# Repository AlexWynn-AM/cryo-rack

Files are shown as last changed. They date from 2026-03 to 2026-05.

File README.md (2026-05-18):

# Cryo Rack System

Cryogenic rack system design and BOM for the CBA-Vertiv collaboration, with applicability to future Adiabatic Machines deployments.

**[Design Package (PDF)](cryo-rack-design-package.pdf)** — Full system design documentation

## Project Goal

Design and procure a cryogenic demonstration rack using off-the-shelf components, targeting a one-month build timeline. The system provides a 4K environment suitable for AQFP processor testing and demonstration.

## Deployments

| Site | Status  | Notes |
|---|---|---|
| Vertiv | Planned | Demo system, primary target |
| CBA | Planned | Independent test infrastructure|
| Adiabatic Machines| Planned | Integration system for Adiabatic Computing|

## Repository Structure

- `bom/` -- Bill of materials in machine-readable YAML, with site-specific overrides
- `decisions/` -- Architecture Decision Records (ADRs) capturing design choices and rationale
- `docs/` -- System architecture, integration notes, and project timeline
- `scripts/` -- Python tooling for BOM analysis, cost rollups, and export
- `specs/` -- Thermal budget, functional requirements, and constraints

## Quick Start

```bash
pip install -r scripts/requirements.lock
python scripts/bom_summary.py bom/bom.yaml
```

`scripts/requirements.lock` pins the full transitive closure for reproducible
environments and is what CI installs. `scripts/requirements.txt` lists the
direct dependencies (also fully pinned with `==`).

### Regenerating the lockfile

When bumping a direct dependency, edit the `==` pin in
`scripts/requirements.txt`, then regenerate the lockfile with
[uv](https://github.com/astral-sh/uv):

```bash
uv pip compile scripts/requirements.txt -o scripts/requirements.lock
```

`pip-compile` from `pip-tools` is an acceptable substitute. Commit both files
together so the lockfile stays in sync with the direct deps.

## BOM Workflow

The master BOM lives in `bom/bom.yaml`. Site-specific overrides (different cryocooler models, shielding configurations, etc.) are in `bom-cba.yaml` and `bom-vertiv.yaml`. Use the summary script to check status, flag missing quotes, and compute cost totals.

## Signal Chain Analysis

The signal chain from the AQFP chip output (~10 uA at 4 K) through wirebond, flex PCB, isolation transformer, cryogenic feedthrough, coax, and room-temperature LNA to the digitizer is modeled in `scripts/signal_chain.py`. It computes per-stage signal amplitude, noise floor, SNR, and bandwidth using Johnson-Nyquist + Friis cascade math.

```bash
python3 scripts/signal_chain.py                       # printable table
python3 scripts/signal_chain.py --json                # JSON for the dashboard
python3 scripts/signal_chain.py --sweep               # SNR vs AQFP drive sweep
python3 scripts/signal_chain_plot.py                  # nominal waterfall plot
python3 scripts/signal_chain_plot.py --scenario worst_loss
python3 scripts/signal_chain_plot.py --scenario worst_noise
```

The waterfall figure (`docs/assets/signal_chain_waterfall.png`) is committed to the repo. Three scenarios bracket the design envelope and are covered by `tests/test_signal_chain.py::TestScenarios`:

| Scenario | Final SNR | Cascaded NF | Bandwidth bottleneck |
|---|---|---|---|
| Nominal | 21.3 dB | 3.37 dB | Room-temp amplifier (1 GHz) |
| Worst loss | 21.4 dB | 7.79 dB | Room-temp amplifier (1 GHz) |
| Worst noise  | 11.0 dB | 6.67 dB | Room-temp amplifier (1 GHz) |

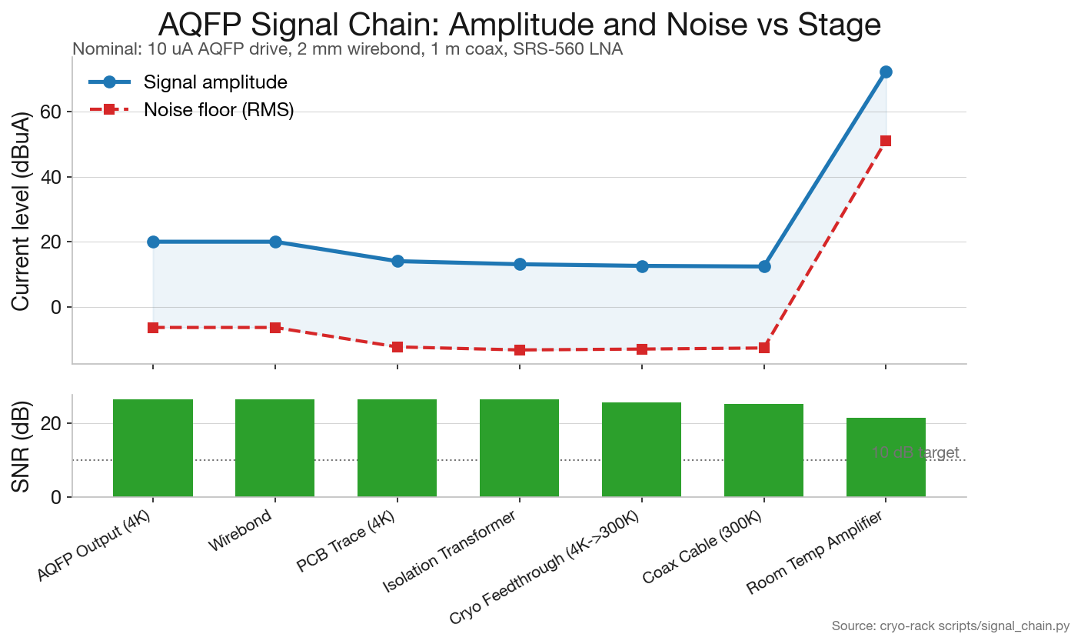
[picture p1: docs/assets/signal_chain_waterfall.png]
Signal chain waterfall — nominal scenario


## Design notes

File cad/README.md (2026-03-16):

# Cryostat CAD Model

FreeCAD 3D model of the cryo-rack cryostat system for AQFP testing.

## Folder Structure

```
cad/
├── README.md                    # This file
├── dimensions.fods              # FreeCAD-linked spreadsheet (Flat ODS)
├── build.sh                     # Build script (generates .FCStd files)
├── build-all.py                 # FreeCAD build script
├── parts/
│   ├── rdk-101d-cold-head.py    # → rdk-101d-cold-head.FCStd
│   ├── sample-stage.py          # → sample-stage.FCStd
│   ├── alumina-disk.py          # → alumina-disk.FCStd
│   ├── radiation-shield.py      # → radiation-shield.FCStd
│   ├── vacuum-vessel.py         # → vacuum-vessel.FCStd
│   ├── top-plate.py             # → top-plate.FCStd
│   ├── thermal-straps.py        # → thermal-straps.FCStd
│   ├── wiring.py                # → wiring.FCStd
│   ├── server-rack.py           # → server-rack.FCStd (42U rack frame)
│   └── cna-11r-compressor.py    # → cna-11r-compressor.FCStd
├── assembly/
│   ├── cryostat-assembly.py     # → cryostat-assembly.FCStd
│   └── rack-assembly.png        # Assembly screenshot
├── exports/                     # STEP files for external sharing
│   └── (generated on demand)
└── reference/
    └── BMC401_cryocooler.stp    # Vendor STEP model (SHI BMC401 cryo cooler)
```

## Building the Models

The `.FCStd` files are generated from Python scripts. To build:

### Option 1: Shell script (recommended)
```bash
cd cad
./build.sh           # Build all parts and assembly
./build.sh clean     # Remove generated files
./build.sh export    # Export to STEP format
```

### Option 2: From FreeCAD GUI
1. Open FreeCAD 0.21 or later
2. Open the Python console (View → Panels → Python console)
3. Run: `exec(open('/path/to/cad/build-all.py').read())`

### Option 3: Individual parts
```bash
cd cad/parts
freecadcmd rdk-101d-cold-head.py  # Generates .FCStd file
```

## Opening the Model

1. Build the models first (see above)
2. Open FreeCAD 0.21 or later
3. Open `assembly/cryostat-assembly.FCStd`
4. All parts are included in the assembly file

## Dimension Sources

### RDK-101D Cold Head (SHI Cryogenics)
- **Source:** SHI RDK-101D outline drawing (request from distributor)
- **Total height:** 442 mm (motor housing to 2nd stage tip)
- **Motor housing:** Ø130 mm
- **1st stage flange:** Ø108 mm at 45K
- **2nd stage cold finger:** Ø52 mm → Ø45 mm at 4K
- **CF flange:** DN63CF (CF4.50)

### Vacuum Vessel
- **Source:** Kurt J. Lesker standard CF components
- **Size:** DN200CF (10" CF flanges, ~200 mm ID)
- **Wall:** 304L stainless steel
- **Length:** Calculated from cold head reach + clearances

### Radiation Shield
- **Source:** Custom fabrication (6061-T6 Al)
- **Default size:** Ø180 mm OD × 250 mm height × 2 mm wall
- **Linked to:** `dimensions.ods` for easy updates

### Sample Stage
- **Source:** Custom fabrication (OFHC Cu, gold-plated)
- **Size:** Ø50 mm × 20 mm thick
- **Mounting:** M3 holes for thermal straps and DUT carrier

### Alumina Disk
- **Source:** CoorsTek / Kyocera polycrystalline Al₂O₃
- **Size:** Ø28 mm × 1.5 mm thick
- **Purpose:** Electrical isolation between cold head and sample stage

### CNA-11R Compressor (SHI Cryogenics)
- **Source:** SHI CNA-11RB specifications
- **Size:** 400 × 484 × 540 mm (H × W × D)
- **Weight:** 65 kg
- **Rack units:** 9U
- **Cooling:** Air-cooled
- **Compatible with:** RDK-101D cold head

### Server Rack
- **Source:** Based on Vertiv VR3100 dimensions
- **Size:** 42U, 600 × 1100 mm (W × D)
- **Rail spacing:** 465.1 mm (19" EIA standard)
- **Style:** Open frame for visibility

## Parametric Variables

All envelope dimensions are linked to `dimensions.ods`. Edit the spreadsheet
to update all linked parts automatically.

| Variable | Default | Unit | Description |
|---|---|---|---|
| `vessel_cf_size` | 200 | mm | DN200CF nominal |
| `vessel_id` | 200 | mm | Inner diameter |
| `vessel_length` | 400 | mm | Calculated from cold head |
| `shield_od` | 180 | mm | Radiation shield OD |
| `shield_height` | 250 | mm | Radiation shield height |
| `shield_wall` | 2 | mm | Shield wall thickness |
| `sample_stage_dia` | 50 | mm | Sample stage diameter |
| `sample_stage_thick` | 20 | mm | Sample stage thickness |
| `strap_width` | 15 | mm | Thermal strap width |
| `coax_od` | 2.2 | mm | 0.086" semi-rigid coax |

## Assembly Notes

- Cold head hangs from top plate (motor outside vacuum)
- Radiation shield thermally connected to 1st stage via Cu straps
- Sample stage thermally connected to 2nd stage via Cu straps
- Alumina disk provides electrical isolation at 4K
- All wiring routes: top plate → 40K heatsink → 4K

## Rack Assembly

The cryostat mounts in a standard 42U server rack with the CNA-11R compressor.

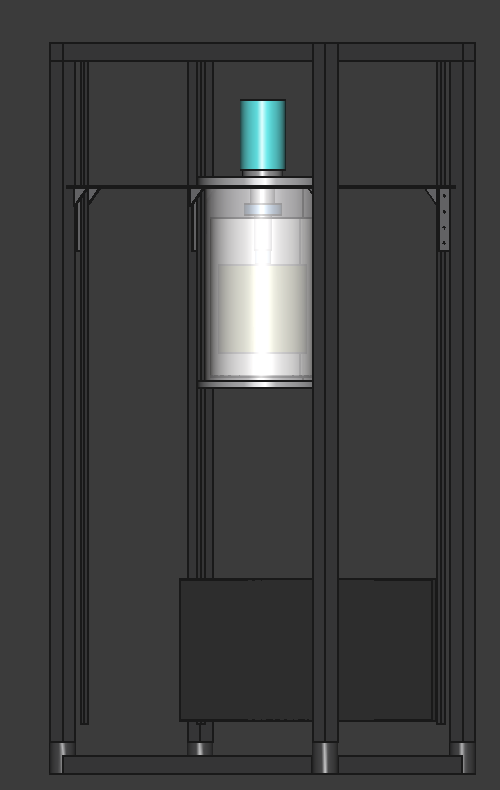
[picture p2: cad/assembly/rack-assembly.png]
Rack Assembly


### Components
- **Server rack:** 42U open frame (600 × 1100 mm), based on Vertiv VR3100
- **Cryostat position:** U35-U42 (near top), mounted on aluminum frame
- **Compressor position:** U1-U9 (bottom)
- **Mounting frame:** 6061-T6 aluminum plate (6mm thick) with center cutout for DN320CF flange

### Rack Specifications
| Parameter | Value |
|---|---|
| Rack units | 42U (1867 mm usable) |
| External width | 600 mm |
| External depth | 1100 mm |
| Rail spacing | 465.1 mm (19" standard) |
| Cryostat clearance | ~40 mm each side between flange and rails |

## Export Instructions

To generate STEP files for external sharing:

### Using build script (recommended)
```bash
./build.sh export
```
Creates `exports/cryostat-assembly.step`

### Manual export
1. Open `assembly/cryostat-assembly.FCStd` in FreeCAD
2. Select all parts in the model tree (Ctrl+A)
3. File → Export → Select STEP format
4. Save to `exports/cryostat-assembly.step`

Individual parts can be exported similarly from their respective files.

## Verification Checklist

- [ ] Cold head dimensions match RDK-101D outline drawing
- [ ] Radiation shield clears 2nd stage + sample stage + wiring
- [ ] Vessel length accommodates full cold head reach
- [ ] Assembly fits within 19" rack width (~450 mm)
- [ ] STEP exports open correctly in other CAD tools

## Calculated Vessel Length

Based on the RDK-101D cold head dimensions and required clearances:

| Component | Z Position | Notes |
|---|---|---|
| Motor top | +245 mm | Outside vacuum |
| CF flange | +25 mm | Mounts to top plate |
| Top plate | 0 mm | **Origin** |
| 1st stage (45K) | -80 mm | Thermal strap attachment |
| 2nd stage tip (4K) | -220 mm | |
| Alumina disk | -222 mm | Electrical isolation |
| Sample stage bottom | -242 mm | Lowest point |

**Recommended vessel length: 300 mm minimum**
- Current design: 400 mm (provides margin for wiring and future changes)
- 50 mm clearance below sample stage

## Related Documents

- `docs/cryostat-assembly.md` — Exploded view diagram and assembly layers
- `docs/thermal-budget.md` — Heat load calculations and shield sizing
- `specs/requirements.md` — System requirements and constraints

## Status

- [x] Folder structure created
- [x] Part scripts written (Python)
- [x] Assembly script written
- [x] Dimension spreadsheet created
- [ ] Generate .FCStd files (run `./build.sh`)
- [ ] Verify dimensions against RDK-101D datasheet
- [ ] Export STEP for Vertiv review

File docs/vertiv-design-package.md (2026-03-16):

---
title: "AQFP Cryo Rack — Design Package"
revision: "0.6"
date: "2026-03-10"
---

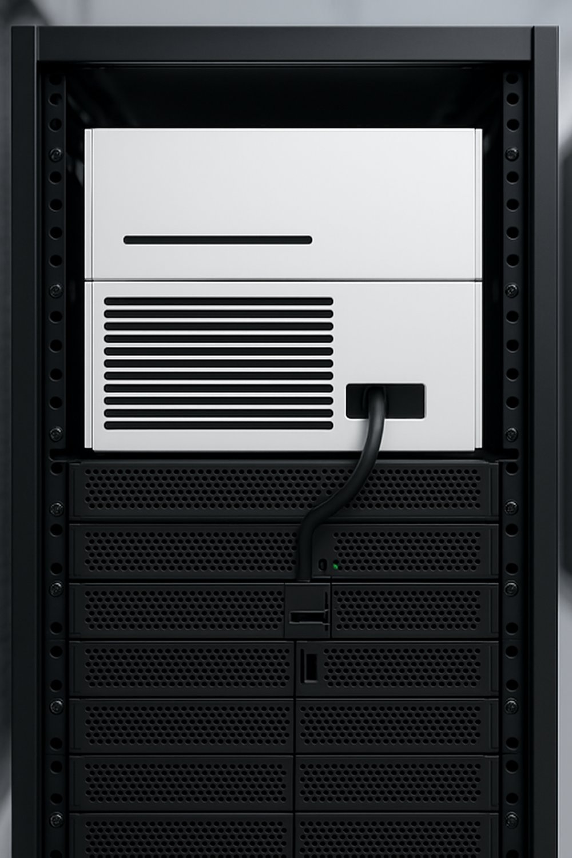
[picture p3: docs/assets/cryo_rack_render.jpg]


**Revision 0.6 — March 2026**

---

## Executive Summary

This document describes the design of a self-contained cryogenic rack
for deploying AQFP (Adiabatic Quantum Flux Parametron) superconducting
processors at 4.2 K. The system is built entirely from off-the-shelf and
standard vacuum components, housed in a 19-inch equipment rack, and designed
for portability between sites.

**Key specifications:**

| Parameter | Value |
|---|---|
| Operating temperature | 4.2 K (second stage), ~40 K (first stage) |
| Cryocooler | SHI RDK-101D + CNA-11RC (GM, air-cooled) |
| Cooling capacity | 100 mW @ 4.2 K, ~6 W @ 45 K |
| Thermal margin | >90% on both stages (with MLI) |
| Power | 120V / 15A standard wall outlet (~2 kW total) |
| Cooling water | Not required |
| Form factor | 19-inch rack (compressor rack-mounted) |
| Vacuum | HiCube 80 Eco turbo station, <10⁻⁸ Torr ultimate |
| Magnetic shielding | FINEMET (40 K), optional Pb foil (4 K) |
| Cooldown time | ~60–90 minutes to 4 K |

**Estimated cost:** ~$52k for the rack build.

**Timeline:** 4 weeks from procurement start to operational, gated by the
12-week cryocooler lead time.

**Deployment plan:** Vertiv (first), then CBA and AM. The system is designed
to be relocated with minimal effort — standard power, air-cooled, modular
construction.

---

## 1. System Architecture

The cryo rack is a self-contained cryogenic deployment platform. A GM cryocooler,
vacuum system, magnetic shielding, and instrumentation are housed in a
standard 19-inch rack, with all signal and power connections accessible from
the front or rear panel.

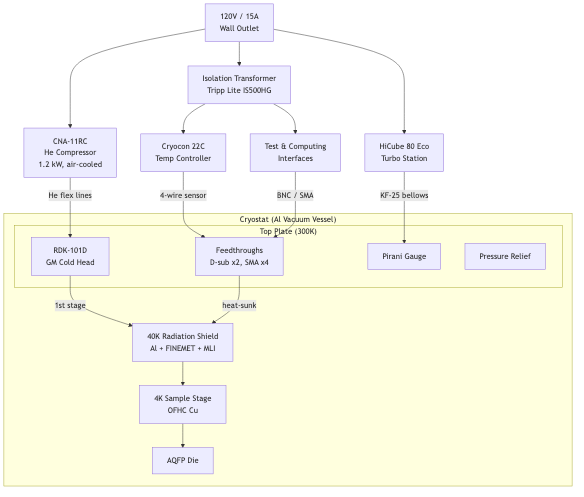
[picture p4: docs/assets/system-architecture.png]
System Architecture


### Thermal stages

The system has three thermal stages:

- **300 K (room temperature):** Vacuum vessel walls, feedthroughs, pump,
  compressor, and all room-temperature electronics.
- **~40 K (first stage):** Aluminum radiation shield with FINEMET
  nanocrystalline magnetic shielding and MLI blankets. Wiring is thermally
  intercepted here.
- **4.2 K (second stage):** OFHC copper sample stage where the AQFP die is
  mounted. Optional superconducting lead foil can be added for residual
  magnetic field attenuation if needed.

### Signal path

DC bias currents are delivered via phosphor bronze twisted pairs, heat-sunk
at 40 K and 4 K. AC clock signals travel on semi-rigid stainless steel
coaxial cables, also thermally intercepted at both stages. All connections
terminate at room-temperature feedthroughs on the cryostat top plate.

### Ground isolation

The cold head body is galvanically continuous with the compressor chassis
through the stainless steel flex lines. The compressor is earth-grounded
through its AC power cord. The GM cycle valve motor produces periodic
current transients (~1 Hz) that propagate through this ground structure.

The system uses two isolated ground domains (see ADR-004):

- **Domain 1 (earth ground):** Building mains → compressor chassis →
  flex lines → cold head → vacuum jacket → rack chassis. Carries
  compressor motor currents. No measurement signals.
- **Domain 2 (isolated measurement ground):** Isolation transformer
  secondary → readout electronics → feedthrough pins → copper backplane
  at 4 K → AQFP circuit ground. Signal and bias currents only.

Isolation is maintained by:

| Location | Component | Function |
|---|---|---|
| 4 K (cold finger) | Polycrystalline alumina disk, 25–30 mm, indium foil both faces | Breaks galvanic path between cryocooler and circuit ground |
| 300 K (feedthroughs) | Ceramic-to-metal hermetic seals | Pins isolated from flange body by design |
| 300 K (power entry) | Tripp Lite IS500HG isolation transformer (500 W, Faraday-shielded) | Isolates readout ground from building mains |
| 300 K (enclosure) | Plastic isolation jacket around cryostat | Prevents accidental contact between cables and vessel |

A plastic enclosure (ABS or acrylic) surrounds the cryostat body,
physically preventing accidental ground contact during assembly and
measurement. All cable routing passes through the enclosure via
insulated grommets at the top plate interface.

---

## 2. Cryostat Assembly

### Design philosophy

All vacuum hardware is standard CF/KF catalog items sourced from multiple
vendors (Kurt Lesker, MDC, Nor-Cal, Ideal Vacuum). Only the radiation shield
and sample stage are custom machined — simple aluminum and copper parts any
machine shop can make. No single-vendor lock-in.

The cryostat is top-loading: the cold head hangs from the top plate with the
cold end pointing down. Feedthroughs are on the top plate or welded side
ports. Pumping connects via KF-25 ports on the vessel body.

### Vacuum vessel material

Two options for the 8" CF vacuum vessel:

| Option | Material | Magnetic (μr) | Procurement | Notes |
|---|---|---|---|---|
| **Aluminum (preferred)** | 6061-T6 Al tube + Atlas bimetal flanges | ~1.00 | Semi-COTS | Al body + SS knife edge; local weld required |
| **Stainless (fallback)** | 304L SS CF nipple | ~1.02–1.10 | COTS (Lesker) | Works with adequate FINEMET shielding |

**Aluminum path:** Purchase Atlas UHV 8" bimetal Al/SS CF weld-neck flanges
and 8" OD 6061-T6 aluminum tube. TIG weld at local shop. Non-magnetic
vessel eliminates trapped flux concerns.

**Stainless path:** Purchase Lesker 8" CF full nipple (304L SS). Faster
procurement but slightly magnetic. The FINEMET shielding (μr ~30,000)
dominates attenuation, so SS vessel permeability is a small contribution
to residual field — acceptable for initial deployment.

### Cross-section

```
  ┌─────────────────────────────────┐
  │         COMPRESSOR              │  CNA-11RC, 120V, rack-mounted
  │         (300 K)                 │
  └──────────┬──────────────────────┘
             │ flex lines (He supply + return)
             │ cold head cable (motor drive)
             │
       ┌─────┴─────┐
       │ COLD HEAD │                      Motor housing sits on top plate
       │  (motor)  │   FT  FT  FT         FT = feedthrough ports (D-sub, SMA)
       │   300K    │   ○   ○   ○          Pirani gauge, pressure relief
       └─────┬─────┘
  ═══════════╪══════════════════════════  ← TOP PLATE (300K)
  ║          │             ○   ○   ║     8" CF multiport cluster flange
  ║    ┌─────┴─────┐               ║     Center bore: CF seal to cold head
  ║    │ 1st stage │               ║     Viton O-ring seal to vessel body
  ║    │  (40 K)   │               ║     (reusable for sample access cycling)
  ║  ┌─┤           ├─┐             ║
  ║  │ └─────┬─────┘ │             ║
  ║  │  strap│  strap│             ║  ← OFHC Cu thermal straps (x2)
  ║  │       │       │             ║
  ║  │  ┌────┴────┐  │             ║
  ║  ├──┤ RAD     ├──┤  ·····      ║  ← RADIATION SHIELD (40K)
  ║  │  │ SHIELD  │  │  :MLI:      ║     6061 Al cylinder + end caps
  ║  │  │ (Al)    │  │  :   :      ║     FINEMET ribbon wrapped on surface
  ║  │  │         │  │  :   :      ║     MLI blankets on outside of shield
  ║  │  │ FINEMET │  │  :   :      ║     Wires heat-sunk here (GE varnish)
  ║  │  │ wrapped │  │  :   :      ║
  ║  │  │         │  │  :   :      ║
  ║  │  │  ┌───┐  │  │  :   :      ║
  ║  │  │  │2nd│  │  │  :   :      ║  ← 2nd STAGE (4K) cold finger
  ║  │  │  │stg│  │  │  :   :      ║
  ║  │  │  ├───┤  │  │  :   :      ║     Cu strap from 2nd stage
  ║  │  │  │   │  │  │  :   :      ║
  ║  │  │  │┌─┐│  │  │  :   :      ║  ← SAMPLE STAGE (4K)
  ║  │  │  ││P││  │  │  :   :      ║     OFHC Cu plate, gold-plated
  ║  │  │  ││ ││  │  │  :   :      ║     Optional Pb foil around DUT
  ║  │  │  │├─┤│  │  │  :   :      ║     Cernox sensor mounted here
  ║  │  │  ││D││  │  │  :   :      ║  ← DUT PCB CARRIER
  ║  │  │  ││U││  │  │  :   :      ║     Wirebonded AQFP die
  ║  │  │  ││T││  │  │  :   :      ║     SMA connectors for RF
  ║  │  │  │└─┘│  │  │  :   :      ║
  ║  │  │  └───┘  │  │  :   :      ║
  ║  │  └─────────┘  │  :···:      ║
  ║  └───────────────┘             ║
  ║                                ║  ← VACUUM VESSEL BODY (300K)
  ║  ○ KF-25 (pump)               ║     6061-T6 Al, 6" OD tube
  ║                                ║     KF ports on top plate
  ║                                ║
  ═════════════════════════════════════  ← BOTTOM PLATE (300K)
                                         Blank 8" CF flange
       │              │
       │              │
  ┌────┴────┐    ┌────┴────┐
  │ HiCube  │    │ Pirani  │
  │ 80 Eco  │    │ gauge   │
  │ (pump)  │    │ CVM211  │
  └─────────┘    └─────────┘
```

### Assembly layers

#### 300 K — Room temperature

| # | Part | Material | Interface |
|---|---|---|---|
| 1 | Equipment rack | Steel | Floor |
| 2 | Compressor (CNA-11RC) | — | 120V wall outlet |
| 3 | Flex lines + cold head cable | SS/Cu | Compressor to cold head |
| 4 | Vacuum vessel body | 6061-T6 Al (or 304L SS) | 8" CF top + bottom (see §2, vessel material) |
| 5 | Top plate | 6061-T6 Al (or 304L SS) | 8" CF, center bore for cold head |
| 6 | Bottom plate | 6061-T6 Al (or 304L SS) | 8" CF blank |
| 7 | Viton O-ring (top plate seal) | Viton | Reusable sample access joint |
| 8 | CF copper gaskets | OFHC Cu | Permanent joints |
| 9 | KF side ports | SS | Welded on vessel body |
| 10 | Pressure relief valve | — | KF-25 port on vessel |
| 11 | Vacuum gauge (Pirani) | — | KF-25 port |
| 12 | HiCube turbo pump station | — | KF-25 bellows hose to vessel |
| 13 | D-sub feedthroughs (x2) | — | CF ports on top plate |
| 14 | SMA feedthroughs (x4) | — | CF ports on top plate |

#### 40 K — First stage

| # | Part | Material | Interface |
|---|---|---|---|
| 15 | Cold head (RDK-101D) | — | CF seal through top plate |
| 16 | Thermal straps (x2) | OFHC Cu braid | 1st stage flange to rad shield |
| 17 | Indium wire | In | Crushed at bolted joints |
| 18 | Radiation shield | 6061-T6 Al | Cylinder + end caps |
| 19 | FINEMET ribbon | Nanocrystalline | Wrapped on rad shield surface |
| 20 | MLI blankets | Al mylar + dacron | Wrapped around shield exterior |
| 21 | Si diode sensor | — | Mounted on shield |
| 22 | Wire heat sinking | GE varnish | Wires anchored to rad shield |

#### 4 K — Second stage

| # | Part | Material | Interface |
|---|---|---|---|
| 23 | Thermal straps (x2) | OFHC Cu braid | 2nd stage to sample stage |
| 23b | Alumina isolation disk | Al₂O₃ (polycrystalline) | Between cold finger and sample stage (see §1, ground isolation) |
| 24 | Sample stage | OFHC Cu | Clamped to cold finger through alumina disk |
| 25 | Lead foil shield (optional) | Pb, 0.1 mm | Wrapped around DUT area |
| 26 | Cernox sensors (x2) | — | 2nd stage + DUT mount |
| 27 | DUT PCB carrier | FR4/Cu | Bolted to sample stage |

### Wiring path

```
External instruments (GS200, 2182A)
       │ DC: BNC/banana cables
       │ RF: SMA cables
       ▼
  ┌─────────────┐
  │ Feedthroughs │  D-sub (DC), SMA (RF) — hermetic, on top plate
  └──────┬──────┘
         │ PhBr wire (DC), SS coax (RF) — inside vacuum
         │
    ┌────┴────┐
    │ 40K     │  Wires thermally anchored (GE varnish on bobbins)
    │ shield  │  Intercepted heat goes to 1st stage
    └────┬────┘
         │
    ┌────┴────┐
    │ 4K DUT  │  DC bias pads + SMA edge-launch on PCB
    │ carrier │  Wirebonded to AQFP die
    └─────────┘
```

### Vacuum path

```
  Atmosphere
       │
  ┌────┴────┐
  │ HiCube  │  Turbo + diaphragm backing pump
  │ 80 Eco  │  KF-25 bellows hose to vessel
  └────┬────┘
       │
  ┌────┴────┐
  │ Vessel  │  SS CF nipple body
  │ interior│  Pirani gauge on KF-25 side port
  │         │  Relief valve on KF-25 side port
  └─────────┘
       ↓ at 4K, cryopumping maintains <1e-6 Torr
```

### Modularity and cryocooler swapping

The top plate is the only cryocooler-specific part. If the cold head
changes (e.g., from RDK-101D to BMC401 or a pulse tube), only the top
plate needs replacement or re-machining (~$400 cost). All other cryostat
components are cold-head agnostic.

---

## 3. Thermal Budget

### Cryocooler capacity

RDK-101D with CNA-11RC compressor at 60 Hz (US power):

| Stage | Temperature | Capacity |
|---|---|---|
| 1st stage | 45–60 K | 3–5 W |
| 2nd stage | 4.2 K | **100 mW** |

### 4 K (second stage) heat budget

| Source | Load (mW) |
|---|---|
| Radiation (40 K to 4 K) | 0.3 |
| DC wire conduction (16x PhBr 36AWG) | 0.1 |
| RF coax conduction (4x SS 0.086") | 2.0 |
| DUT dissipation (AQFP: nW–uW) | ~0 |
| **Total** | **~2.4** |
| **Available** | **100** |
| **Utilization** | **2.4%** |

### 40 K (first stage) heat budget

| Source | With MLI | Without MLI |
|---|---|---|
| Radiation (300 K to 40 K) | 120 mW | 1,800 mW |
| DC wire conduction | 3 mW | 3 mW |
| RF coax conduction | 35 mW | 35 mW |
| **Total** | **~160 mW** | **~1,840 mW** |
| **Available** | **~3,000 mW** | **~3,000 mW** |
| **Utilization** | **5%** | **61%** |

Both stages have large thermal margin. MLI is recommended but not
strictly required at the baseline shield size (100 mm diameter). For
larger shields (200–300 mm), MLI is mandatory — see appendix.

### Shield sizing (how big can we go?)

With MLI, shield size is thermally unconstrained for any rack-mount design:

| Shield (dia x H) | Area | With MLI | Without MLI |
|---|---|---|---|
| 100 x 150 mm | 0.063 m² | 95 mW **(3%)** | 1.4 W (48%) |
| 200 x 300 mm | 0.251 m² | 376 mW **(13%)** | 5.8 W (OVER) |
| 300 x 400 mm | 0.518 m² | 777 mW **(26%)** | 12 W (OVER) |

A 200–300 mm diameter shield provides generous working space for
multiple DUTs and complex wiring, uses only 13–26% of the first-stage
budget with MLI, and fits comfortably in a 19-inch rack (450 mm between
rails).

---

## 4. Cryocooler Selection

### Comparison of quoted options

| Parameter | SHI RDK-101D | SHI RDC-02K | Bama BMC401 | Cryomech PT205 |
|---|---|---|---|---|
| **Type** | GM | GM | GM | Pulse tube |
| **Quoted price** | $27,230 | $37,155 | $13,000 | $42,325 |
| **Lead time** | 12 weeks | 12 weeks | 4 weeks | 36–40 weeks |
| **4 K capacity** | 0.1 W | 0.2 W | 0.16 W | 0.1–0.3 W |
| **40 K capacity** | ~6 W @ 45 K | ~6 W @ 45 K | 3 W @ 45 K | TBD |
| **Min temp** | ~3.5 K | < 2 K | < 2.3 K | 5–6 K |
| **120V / 15A** | **Yes** | **Yes** | **No** (220V) | **Likely yes** |
| **Cooling** | Air | Air | Unconfirmed | Air |
| **Compressor power** | ~1.2 kW | ~1.2 kW | ~1.5 kW | ~1.5 kW |
| **Maintenance** | 10,000 hr | 10,000 hr | 10,000 hr | ~20,000 hr |
| **Vibration** | Moderate (GM) | Moderate (GM) | Moderate (GM) | Low (PT) |

### Selection rationale

**Primary: SHI RDK-101D + CNA-11RC** — 120V plug-and-play, air-cooled,
well-established platform with extensive support. 12-week lead time.

**Upgrade option: SHI RDC-02K + CNA-11RC** — same compressor and rack
integration as the RDK-101D, but 2x the 4 K capacity (0.2 W) and
guaranteed < 2 K base temperature. $10k premium over the RDK-101D.
Relevant if Phase 2 wiring loads grow or sub-4 K operation is needed.

**Backup: Bama BMC401** — half the cost, 4-week delivery, but 220V/50Hz
compressor is not compatible with standard 120V/15A outlets. Under
evaluation for 60 Hz compatibility and potential pairing with SHI CNA-11RC
compressor.

**Not selected: Cryomech PT205** — 36–40 week prototype lead time and
highest cost eliminate it for near-term build. Low vibration and longer
maintenance interval do not materially benefit AQFP electrical testing.
Reconsidering for future permanent installations.

---

## 5. Bill of Materials

<!-- BOM_TABLES -->

*Full BOM is auto-generated from `bom/bom.yaml` (rev 0.6) by the build
script. The tables below show active items only (qty > 0). Reference-only
options (alternative cryocoolers, scroll pump) are excluded from cost
totals.*

---

## 6. Site Requirements — Vertiv

### Power

| Requirement | Specification |
|---|---|
| Outlet type | NEMA 5-15 (standard US 120V / 15A) |
| Circuits needed | 2 recommended (compressor on one, instruments on another) |
| Total power draw | ~2–3 kW |
| Compressor | ~1.2 kW (CNA-11RC), direct to building mains (earth-grounded) |
| Turbo pump | ~150 W (HiCube 80 Eco) |
| Instruments | ~200 W behind isolation transformer (Tripp Lite IS500HG, 500 W) |

No special electrical work required. Standard office/lab outlets are
sufficient. The readout electronics are powered through a rack-mounted
isolation transformer to maintain a clean, isolated measurement ground
(see §1, ground isolation).

### Space

| Requirement | Specification |
|---|---|
| Rack | 19-inch standard, ~20U minimum |
| Rack footprint | ~0.6 x 0.8 m |
| Compressor | Rack-mounted (CNA-11RC fits 19-inch rack) |
| Clearance | Allow ~0.5 m behind rack for cable routing and airflow |
| Cryostat position | Top of rack or adjacent bench |

### Environment

| Requirement | Specification |
|---|---|
| Ambient temperature | 15–30 C (standard lab/office) |
| Cooling water | **Not required** (air-cooled compressor) |
| Ventilation | Standard room HVAC sufficient; compressor rejects ~1–2 kW as heat |
| Floor loading | ~150–200 kg total (rack with compressor + cryostat) |
| Vibration isolation | Not required for AQFP testing |

### Network (optional)

- Ethernet for Cryocon 22C remote temperature monitoring
- USB for instrument control (GS200, 2182A)

### Facility preparation checklist

- [ ] Confirm availability of 2x 120V / 15A outlets near rack location
- [ ] Confirm 19-inch rack (Vertiv may supply) or designate rack location
- [ ] Confirm rack has sufficient depth for compressor (~600 mm)
- [ ] Confirm adequate room ventilation for ~2 kW heat rejection
- [ ] Assign Ethernet drop if remote monitoring desired

---

## 7. Timeline

**Target:** Operational cryo rack within 4 weeks of procurement start.

| Week | Activities |
|---|---|
| **1** | Finalize cryocooler selection. Send RFQs. Order long-lead items. Complete cryostat detailed design. |
| **2** | Place all orders. Commission custom machining (radiation shield, sample stage). Begin rack layout. |
| **3** | Receive and inspect components. Assemble cryostat. Install magnetic shielding. Wire feedthroughs. Room-temperature functional tests. |
| **4** | Leak check vacuum system. Pump down and cooldown. Verify base temperature. Measure residual magnetic field. Functional test with AQFP die (if available). |

### Critical path

The 12-week cryocooler lead time (SHI RDK-101D) gates the overall
schedule. All other components have 1–2 week lead times. During the
cryocooler wait:

- Complete cryostat detailed design using outline drawing dimensions
- Procure and assemble all non-cryocooler components
- Perform room-temperature vacuum and wiring tests
- Prepare DUT carriers and test fixtures

If BMC401 (4-week lead) is selected as backup, the full build can be
completed in approximately 5–6 weeks end-to-end.

---

## 8. Open Items and Risks

### Open actions

| # | Action | Owner | Status |
|---|---|---|---|
| 1 | Re-quote SHI RDK-101D (Quote 5618 expired). Specify CF flange option. | Procurement | Pending |
| 2 | Confirm Cryomech PT205 120V availability when re-quoting | Procurement | Pending |
| 3 | Clarify Bama BMC401 mounting pattern, 60 Hz compatibility, SHI compressor compatibility | Engineering | Pending |
| 4 | Finalize cryostat vessel length from RDK-101D outline drawing dimensions | Engineering | Pending |
| 5 | Detailed top plate port layout (feedthrough count and placement) | Engineering | Pending |
| 6 | DUT PCB carrier design (depends on AQFP die pinout) | Engineering | Pending |

### Risk register

| Risk | Impact | Mitigation |
|---|---|---|
| Cryocooler lead time (12 wk) | Schedule slip | BMC401 backup (4 wk). Pre-assemble all other components. |
| RDK-101D quote expired | Price/availability change | Re-quote immediately. Budget has margin. |
| BMC401 not 120V compatible | Limits portability | Investigate SHI CNA-11RC + BMC401 cold head hybrid. |
| Custom machining delays | 1–2 week slip | Use Protolabs/Xometry for fast-turn; simple parts. |
| MLI installation quality | Higher thermal load | >90% margin on both stages absorbs poor MLI. |
| Vacuum leak at O-ring seal | Pumpdown failure | Turbo pump can maintain vacuum continuously. Viton adequate to 10⁻⁷ Torr. |

---

## Appendix A: MLI Sourcing

10-layer MLI blankets are recommended for radiation shields larger than
150 mm diameter. Material needed for a 200 mm x 300 mm shield:
~2 m² each of reflector and spacer.

| Option | Material | Cost | Lead Time |
|---|---|---|---|
| **DIY (recommended)** | Aluminized mylar (Amazon) + polyester netting (Joann Fabric) | $50–75 | Days |
| **Professional** | Double-aluminized PET (Dunmore) + Dacron netting | $300–500 | 1–2 weeks |
| **Pre-made blankets** | Custom blankets (FrakoTerm, Poland) | $500+ | 2–4 weeks |

DIY MLI has been validated by WSU HYPER lab as comparable in thermal
performance to professional MLI. With >90% thermal margin, DIY is more
than adequate.

MLI adds ~15–30 minutes to pumpdown time due to additional outgassing
surface area. This is a manageable trade-off.

## Appendix B: 3D Printed Parts (PLA at 4 K)

PLA has been validated at 4 K for non-thermally-conductive structural
parts. Low thermal conductivity is a feature for thermal isolation.

**Suitable for 3D printing:**

| Part | Benefit |
|---|---|
| Wire routing bobbins (40 K) | Custom geometry for wire routing |
| DUT mount adapter | Fast iteration as DUT pinout changes |
| Magnetic shield brackets | Hold FINEMET (+ optional Pb foil) in position |
| Thermal isolation standoffs | Low-conductivity spacers between stages |
| Feedthrough strain reliefs | Cable management |

**Must remain metal:** Radiation shield (Al), sample stage (Cu),
vacuum vessel (SS), thermal straps (OFHC Cu).

PLA outgasses at room temperature in vacuum but this is handled by
the turbo pump during pumpdown (adds a few minutes). Once cold,
outgassing drops to near zero.

## Appendix C: CAD Render

FreeCAD model of the complete rack-mounted system:

Rack Assembly

*42U rack with cryostat mounted at U35 (top) and CNA-11R compressor at U1 (bottom).
6mm aluminum mounting frame supports cryostat flange on 19" rails.*

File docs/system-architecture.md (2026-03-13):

# System Architecture

## Overview

The cryo rack is a self-contained cryogenic deployment platform for AQFP superconducting processors. It houses a GM cryocooler, vacuum system, magnetic shielding, and instrumentation in a standard 19" rack, with all signal and power connections accessible from the front or rear panel.

## Block Diagram

```
┌─────────────────────────────────────────────────┐
│  19" Rack                                        │
│                                                   │
│  ┌──────────────┐    ┌────────────────────────┐  │
│  │ Instruments  │    │ Cryostat               │  │
│  │              │    │                        │  │
│  │ Temp Monitor │    │  300K ──── Feedthroughs│  │
│  │ Bias Sources │    │    │                   │  │
│  │ Clock Gen    │    │  40K ──── FINEMET      │  │
│  │ DAQ/Scope    │    │    │      shield       │  │
│  │              │    │   4K ──── Pb shield    │  │
│  │              │    │    │      DUT mount    │  │
│  └──────────────┘    │    └── AQFP die       │  │
│                      └────────────────────────┘  │
│  ┌──────────────┐    ┌────────────────────────┐  │
│  │ He Compressor│◄──►│ Flex lines to cold head│  │
│  │ (+ chiller)  │    └────────────────────────┘  │
│  └──────────────┘                                 │
│  ┌──────────────┐                                 │
│  │ Turbo + Scroll│   Vacuum pumping              │
│  │ Pump Stack    │                                │
│  └──────────────┘                                 │
└─────────────────────────────────────────────────┘
```

## Thermal Stages

The system has three thermal stages. The 300K (room temperature) stage holds the vacuum vessel walls, feedthroughs, and all room-temperature electronics. The first stage at approximately 40K provides radiation shielding and a thermal intercept for wiring; the FINEMET nanocrystalline magnetic shield is wrapped on the 40K radiation shield. The second stage at 4.2K is where the AQFP die is mounted, surrounded by a superconducting lead foil shield for residual field attenuation.

## Signal Path

DC bias currents are delivered via phosphor bronze or manganin twisted pairs, heat-sunk at 40K and 4K. AC clock signals at GHz frequencies travel on semi-rigid or flexible stainless-steel coaxial cables, also thermally intercepted at both stages. Signal readout follows the reverse path. All connections terminate at room-temperature feedthroughs on the cryostat top plate.

## Vacuum

The cryostat is evacuated by a turbomolecular pump backed by an oil-free scroll pump. Once cold, cryopumping on the 4K surfaces maintains vacuum without continuous pumping, though the turbo may remain connected for safety.

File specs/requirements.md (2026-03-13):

# System Requirements

## Functional Requirements

1. Provide a 4.2 K environment with sufficient volume to mount and test AQFP processor die.
2. Cryocooler cooling capacity: >= 100 mW at 4.2 K (second stage), >= 6 W at 45 K (first stage). Thermal budget shows ~16 mW / ~2 W actual load (see `specs/thermal-budget.md`).
3. Ambient magnetic field at the DUT must be < 5 uT (with shielding, target < 100 nT using superconducting Pb shield at 4 K).
4. Support DC bias wiring (16+ conductors, uA precision) from 300 K to 4 K with thermal intercepts at 40 K.
5. Support multi-phase AC clock delivery at GHz frequencies via 4 coax lines from 300 K to 4 K.
6. Support signal readout from 4 K to 300 K with adequate bandwidth.
7. Cool-down time from 300 K to 4 K base temperature should be < 12 hours.
8. System must be self-contained in a standard 19" rack form factor.

## Constraints

- **Timeline:** Procurement and assembly within approximately 4 weeks (target operational by 2026-04-10).
- **Budget:** Estimated ~$75-85k all-in for RDK-101D configuration (see BOM). Use COTS components where possible.
- **Power:** 120 V single-phase preferred for site portability. Total system power ~2-3 kW with RDK-101D air-cooled compressor.
- **Cooling water:** Not required (air-cooled CNA-11C compressor selected per ADR-002).
- **Transportability:** System must be movable between Vertiv, CBA, and AM. Avoid permanent installations. Air-cooled compressor and 120 V operation support this.

## Deployment Sites

1. **Vertiv** — first deployment, primary demo site
2. **CBA** — second deployment, leveraging existing lab infrastructure
3. **AM** — third deployment, shortly after CBA

## Future Requirements (Phase 2)

- Optical I/O path: fiber feedthroughs, VCSEL driver at 300 K, InGaAs photodiode at 4 K.
- Higher channel count for larger AQFP die (may require upgrading to RDK-408D2 class cooler).
- Integration with LPDDR5X memory subsystem at 300 K.

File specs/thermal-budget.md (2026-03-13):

# Thermal Budget

**Moved to [docs/thermal-budget.md](../docs/thermal-budget.md)** — contains
calculated heat loads, shield sizing analysis, and margin assessment.

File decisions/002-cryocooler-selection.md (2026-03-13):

# ADR-002: Cryocooler Selection

**Status:** proposed  
**Date:** 2026-03-10  
**Deciders:** Team

See also: [docs/cryocooler-comparison.md](../docs/cryocooler-comparison.md) for full quoted comparison table.

## Context

The cryo rack needs a two-stage cryocooler to reach 4.2 K for AQFP testing. The system must be operational at Vertiv within ~4 weeks, then move to CBA and AM. Key drivers are lead time, cost, 120 V plug-and-play operation, and sufficient cooling for a minimal-wiring first build.

The original BOM placeholder spec'd ">= 1 W at 4.2 K" (RDK-408D2 class), but the actual thermal budget for the first build is ~16 mW at 4 K and ~2 W at 40 K — well within the capacity of a smaller cooler.

Quotes have been received for four options (all in `bom/quotes/`).

## Options Considered

### Option A: Sumitomo RDK-101D + CNA-11RC — $27,230 (Recommended)

- **4 K capacity:** 0.1 W at 4.2 K
- **40 K capacity:** ~6 W at 45 K
- **Compressor:** CNA-11RC, air-cooled, 100–120 V single-phase, 1.0–1.2 kW
- **120 V / 15 A:** Yes — 1.2 kW well within 1,440 W continuous limit
- **Lead time:** 12 weeks ARO
- **Quote:** SHI Quote 5618, 11/7/2025 (expired — re-quote needed)
- **Type:** GM
- **Pros:**
  - 120 V plug-and-play — works at any site without special power
  - Air-cooled — no chilled water needed
  - Well-established platform, extensive support ecosystem
  - Adequate margin for minimal AQFP test (~16% utilization at 4 K)
  - 10,000 hr maintenance interval, field-serviceable
- **Cons:**
  - 12-week lead time
  - Limited headroom for Phase 2 expansion
  - Moderate vibration at cold stage (GM displacer)

### Option B: Bama BMC401 + HC104F — $12,500 (Backup)

- **4 K capacity:** 0.16 W at 4.2 K
- **40 K capacity:** 3 W at 45 K
- **Compressor:** HC104F — voltage/cooling TBD, must confirm with vendor
- **120 V / 15 A:** Unknown — must confirm. Chinese equipment often defaults to 220 V / 50 Hz.
- **Lead time:** 4 weeks
- **Quote:** Bama email, RMB 90,000 EXW (active)
- **Type:** GM
- **Pros:**
  - Lowest cost by far (less than half of SHI)
  - Fastest lead time (4 weeks)
  - Higher 4 K capacity than RDK-101D (0.16 W vs 0.1 W)
  - Reaches < 2.3 K base temperature
- **Cons:**
  - Less established in Western cryo labs — smaller support ecosystem
  - 120 V / cooling method unconfirmed
  - 1st stage only 3 W @ 45 K (vs 6 W for SHI) — tighter margin at 40 K
  - Flex lines/cables may not be included in quote
  - 10,000 hr maintenance (same as SHI)

### Option C: Cryomech PT205 + CP103A — $42,325 (Reference only)

- **4 K capacity:** 0.1–0.3 W at 5–6 K (prototype)
- **Compressor:** CP103A, 208/220 V 1-ph 60 Hz, air-cooled, ~1.5 kW, 19" rack
- **120 V / 15 A:** No — requires 208/220 V dedicated circuit (NEMA 6-15/6-20)
- **Lead time:** 36–40 weeks ARO (prototype)
- **Quote:** Bluefors CTI Quote 0010037, 10/24/2025 (expired)
- **Type:** Pulse tube
- **Pros:**
  - No moving parts at cold end — low vibration, ~20,000+ hr maintenance
  - Rack-mountable compressor
- **Cons:**
  - Prototype — 36–40 week lead time rules it out for near-term build
  - Most expensive option
  - Requires 208 V — not plug-and-play at arbitrary sites
  - Must be operated near-vertical (pulse tube orientation sensitivity)
  - 5–6 K operation, not guaranteed < 4.2 K

### Option D: SHI RDC-02K + CNA-11RC — $37,155

- **4 K capacity:** 0.2 W at 4.2 K
- **40 K capacity:** ~6 W at 45 K
- **Compressor:** CNA-11RC, air-cooled, 100–120 V single-phase, 1.0–1.2 kW
- **120 V / 15 A:** Yes — same compressor as Option A
- **Lead time:** 12 weeks ARO
- **Quote:** SHI Quote 5617 (expired — re-quote needed)
- **Min temp:** < 2 K (guaranteed)
- **Type:** GM
- **Pros:**
  - 2× the 4 K capacity of the RDK-101D (0.2 W vs 0.1 W) — more headroom for Phase 2 wiring
  - Guaranteed < 2 K base — enables future sub-4 K experiments if needed
  - Same compressor, flex lines, and rack integration as Option A
  - 120 V plug-and-play, air-cooled
- **Cons:**
  - $10k premium over Option A for capacity not needed in the first build
  - Slightly heavier cold head (~6 kg vs ~4 kg)
  - 12-week lead time (same as Option A)
  - Quote expired — re-quote needed

### Previously considered (not quoted)

- **RDK-408D2 + CSW-71D:** ~$40–60k, water-cooled, 208 V, overkill for this build.
- **Cryomech PT410:** ~$50–70k, water-cooled, 208 V, overkill.

## Decision

**Select RDK-101D + CNA-11RC as primary (Option A). BMC401 as backup/fast-start (Option B).**

The PT205 pulse tube is not viable for the near-term build due to 36–40 week prototype lead time, 208 V power requirement, and higher cost. It should be reconsidered for a future permanent installation.

## Rationale

1. **Thermal budget fit:** ~16 mW at 4 K and ~2 W at 40 K — both options cover this with margin.
2. **120 V plug-and-play:** The CNA-11RC runs on a standard wall outlet. The Cryomech CP103A does not. This is a hard constraint for a portable demo rack.
3. **GM reliability is sufficient:** 10,000 hr maintenance interval gives > 1 year continuous before service. For a demo/prototype platform this is more than adequate.
4. **Pulse tube advantages don't help here:** Low vibration matters for scanning probe or optical alignment, not for AQFP electrical testing. The 2x maintenance interval doesn't justify 3x cost and 8x lead time.
5. **BMC401 is the fastest path** if we need to move immediately — 4 weeks, $12.5k. Must confirm 120 V compatibility.

## Consequences

- Cryostat design must be compatible with the RDK-101D cold-head flange (outline drawing in `bom/quotes/`).
- If BMC401 compressor is 220 V only, it needs a step-up transformer or dedicated circuit — reduces its plug-and-play advantage.
- Phase 2 may require a cooler upgrade — design cryostat top plate to accept larger cold heads if practical.
- Water chiller line item not needed (both options are air-cooled).

## Open Actions

1. Re-quote SHI RDK-101D (Quote 5618 expired 12/7/2025)
2. Confirm BMC401 compressor specs: input voltage (120 V / 60 Hz available?), air vs water cooling, flex line inclusion
3. Make go/no-go decision on Option A vs B based on voltage confirmation and schedule

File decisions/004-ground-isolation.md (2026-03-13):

# ADR-004: Ground Isolation Architecture

**Status:** proposed  
**Date:** 2026-03-13  
**Deciders:** Team

See also: [docs/ground_isolation_memo.docx](../docs/ground_isolation_memo.docx) for full analysis.

## Context

The RDK-101D cold head is galvanically continuous with the CNA-11RC compressor chassis through the stainless steel body and flex lines. The compressor chassis is earth-grounded through its AC power cord. The GM cycle valve motor produces periodic current transients (~1 Hz) that propagate through this ground structure.

If the AQFP copper backplane at 4 K is bolted directly to the second-stage cold finger, the circuit ground reference is defined in part by the compressor ground, injecting motor noise into the measurement return path.

Two isolation points are needed: one at the cold interface (4 K) and one at the room-temperature power entry.

## Options Considered

### Option A: Single isolation transformer for everything

Compressor, cold head, and readout electronics all sit behind one isolation transformer, sharing a single isolated ground domain. Eliminates building mains noise and is simple (one transformer, one plug). However, the compressor motor's switching currents still flow through the shared ground bus, and the readout electronics see this as noise on their voltage reference. Trades building mains noise for compressor motor noise.

### Option B: Isolate only the readout (Recommended)

Compressor stays on building mains, earth-grounded for safety and code compliance. Readout electronics get their own small isolation transformer (500 W–1 kW) with a clean, quiet, isolated ground reference. The alumina disk isolates the 4 K backplane from the cold head structure. The only connection between the readout ground domain and the 4 K circuit is the dedicated ground wires through the DC feedthrough pins.

No shared conductor carries both motor current and signal return current at any point in the system. This is the standard approach used in SQUID magnetometry and other sensitive superconducting measurements.

COTS units: Tripp Lite IS500HG (500 W, 120 V, UL 60601-1, Faraday-shielded, ~$200–300) or IS1000HG (1 kW). Compact enough for a 1U–2U rack shelf.

### Option C: Two separate isolation transformers

Compressor on one isolation transformer, readout on another. Provides maximum isolation from building mains for both, but introduces a ground loop risk. If the compressor's isolated ground and the readout's isolated ground are inadvertently connected through the cryostat body (compressor → flex lines → cold head → vacuum jacket → feedthrough shell → readout ground), a ground loop forms. The alumina disk breaks one leg of that loop, but any feedthrough shield, cable braid, or debug probe touching the vacuum jacket re-establishes it. Two separate isolated ground domains with an accidental single-point connection is worse than a deliberate single-point design. Not recommended.

## Decision

**Select Option B: isolate only the readout electronics.**

Two ground domains with a single, well-defined interface:

- **Domain 1 (earth ground):** Building mains earth → compressor chassis → stainless flex lines → cold head body → cryostat vacuum jacket → rack chassis. Carries compressor motor currents. No measurement signals.
- **Domain 2 (isolated measurement ground):** Isolation transformer secondary → readout electronics ground bus → dedicated ground wires through DC feedthrough pins → copper backplane at 4 K → AQFP circuit ground. Carries only signal and bias currents.

Isolation between domains is maintained by:
- Alumina disk at 4 K (between cold finger and backplane)
- Ceramic seals in hermetic feedthroughs at 300 K (pins isolated from flange body by design)

## Consequences

- **BOM additions:** alumina disk (~$30, off-the-shelf), indium foil for both faces (already in BOM), Tripp Lite IS500HG isolation transformer (~$250).
- **Assembly discipline:** No readout cable shield, coax braid, ground lug, or debug probe ground may touch the cryostat body, vacuum jacket, or rack chassis. Every electrical connection between the readout and the cryostat must pass through the feedthrough pins only. Document this in the integration checklist.
- **Thermal impact:** Alumina disk adds a fraction of a kelvin to the base temperature at the backplane. Negligible given >90% thermal margin.
- **Cryostat assembly change:** Sample stage is no longer bolted directly to cold finger. Stack is now: cold finger → indium foil → alumina disk → indium foil → copper backplane.
- **Feedthrough selection:** Standard ceramic-to-metal hermetic feedthroughs (Ceramaseal, Lesker) maintain isolation by design. Any shielded/coax lines where the shield connects to the flange must be avoided or modified.

## Open Questions

1. Confirm RDK-101D CF flange size (believed CF4.50 / DN63CF) — affects zero-length reducer selection if vessel is upsized.
2. Isolation transformer sizing — 500 W likely sufficient for readout alone; verify total draw of DAC/ADC, bias sources, clock generator.
3. Establish debug access protocol: no scope probe ground or clip lead may touch cryostat body during measurement. Label feedthrough connectors accordingly.

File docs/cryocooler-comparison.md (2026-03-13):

# Cryocooler Options — Quoted Comparison

Last updated: 2026-03-11 (BOM rev 0.7)

## Quoted Options

| Parameter | **Bama BMC401** | **SHI RDK-101D** | **SHI RDC-02K** | **Cryomech PT205** |
|---|---|---|---|---|
| **Type** | GM | GM | GM | Pulse tube |
| **Quoted price** | $13,000 (USD direct) | $27,230 | $37,155 | $42,325 |
| **Lead time** | 4 weeks | 12 weeks | 12 weeks | 36–40 weeks |
| **2nd stage (4.2 K)** | 0.16 W | 0.1 W | 0.2 W | 0.1–0.3 W (prototype) |
| **1st stage** | 3 W @ 45 K | ~6 W @ 45 K | ~6 W @ 45 K | TBD ("not as important") |
| **Min temp** | < 2.3 K | ~3.5 K | < 2 K (guaranteed) | 5–6 K |
| **120 V / 15 A compatible** | **Marginal** — HC104F is 220V/1.5kW; with step-up xfmr draws 12.5A @ 120V (tight on 15A, OK on 20A). 60Hz confirmed. | **Yes** (CNA-11RC, 1.0–1.2 kW) | **Yes** (same CNA-11RC) | **Likely yes** — quote said 208/220V but ~1.5 kW = 12.5A @ 120V; confirm 120V option |
| **Cooling** | TBD — confirm | Air-cooled | Air-cooled | Air-cooled |
| **Rack-mountable compressor** | TBD | Yes (CNA-11 series) | Yes (CNA-11 series) | Yes (CP103A, 19" rack) |
| **Compressor input power** | 1.5 kW (confirmed) | ~1.0–1.2 kW | ~1.0–1.2 kW | ~1.5 kW |
| **Cold head mass** | 8 kg | ~4 kg | ~6 kg | TBD (prototype) |
| **Maintenance interval** | 10,000 hr | 10,000 hr | 10,000 hr | ~20,000+ hr (est.) |
| **Vibration at cold stage** | Moderate (GM) | Moderate (GM) | Moderate (GM) | Low (pulse tube) |
| **Quote status** | Active | Expired — re-quote | Expired — re-quote | Expired — re-quote |
| **Quote ref** | Bama email Oct 2025, $7k+$6k USD | SHI Quote 5618 | SHI Quote 5617 | Quote 0010037, Ticket 72680 |
| **Vendor** | Bama Superconductor (Suzhou) | SHI Cryogenics of America | SHI Cryogenics of America | Bluefors CTI (Cryomech) |

### Alternative Compressor: attocube IGLU

The [IGLU compressor](https://www.attocube.com/en/products/cryostats/compact-mobile-cryogenics/iglu-compressor) is a standalone rack-mountable helium compressor (~$40k est.) confirmed compatible with the RDK-101D cold head. 19" rack form factor, ~1 kW input, air-cooled, orientation-free, oil-free. Natively 230V but at ~1 kW a 120V step-up transformer is trivial (~8.3A). Decouples the compressor from the cold head vendor. However, the CNA-11RC bundled in the SHI quote is $13k and does 120V natively — so the IGLU is 3x the cost for the same function. Mainly interesting for future modularity or if rack density is critical.

### 120 V / 15 A Notes

A standard US NEMA 5-15 outlet supplies 120 V at 15 A (1,800 W max, 1,440 W continuous per NEC 80% rule).

- **SHI CNA-11RC**: 1.0–1.2 kW input. Runs on 100–120 V single-phase. Well within 15 A / 1,440 W continuous. **Plug and play.**
- **Cryomech CP103A**: Quote specified 208/220 V, 1-ph, 60 Hz, ~1.5 kW. However, at 1.5 kW a 120 V version would draw only ~12.5 A — well within 15 A. Cryomech (US manufacturer, Syracuse NY) routinely makes compressors in multiple voltage variants. **Likely available in 120 V — confirm when re-quoting.** If so, this is also plug-and-play.
- **Bama HC104F**: 220 V, **1.5 kW confirmed** (10A Chinese outlet). **60 Hz confirmed OK** — Bama can set before shipping. With a ~$40 step-up transformer (120V→220V, 1.5 kW), draws **~12.5 A @ 120 V**. Exceeds the NEC 80% continuous limit (12 A) on a 15 A breaker, but **fine on a 20 A circuit (NEMA 5-20)**. Much better than the 3 kW / 25 A originally estimated. BMC401 cold head is **NOT compatible** with SHI CNA-11 compressor (different motor drive).

## Pulse Tube vs GM — Reliability & Tradeoffs

### GM (Gifford-McMahon) — BMC401, RDK-101D, RDC-02K

- **Moving parts at cold end**: mechanical displacer with seal, driven by motor.
- **Maintenance interval**: ~10,000 hours (~14 months continuous). Displacer seal and regenerator service.
- **Failure modes**: well-characterized. Seal wear is gradual — performance degrades before failure. Field-serviceable with standard tool kits (SHI includes one in quote).
- **Vibration**: moderate displacement at cold stage (~10–25 μm) due to displacer motion. For AQFP testing this is generally acceptable — AQFP chips are not mechanically sensitive in the way optical cavities or STM tips are.
- **Orientation**: can operate in any orientation (some models have restrictions, but SHI RDK-101D is flexible).
- **Cooldown**: relatively fast. BMC401 < 150 min, RDK-101D typically ~60–90 min.

### Pulse Tube — PT205

- **No moving parts at cold end**: the oscillating gas column replaces the mechanical displacer. All moving parts are in the remote compressor.
- **Maintenance interval**: ~20,000–30,000 hours (~2–3 years continuous). Compressor valve maintenance only.
- **Failure modes**: less wear overall, but when issues occur they tend to be in the rotary valve or compressor — still field-serviceable. Less community experience with the PT205 specifically (it's a prototype).
- **Vibration**: significantly lower at cold stage (no displacer motion). Relevant for vibration-sensitive measurements (scanning probe, optical interferometry), but **not a major differentiator for AQFP electrical testing**.
- **Orientation**: pulse tubes are more sensitive to tilt. Most must operate within ~5° of vertical. This matters for shipping/setup but not for steady-state rack operation.
- **Cooldown**: can be slower than GM for the same capacity due to lower specific cooling at high temperatures.

### Recommendation for This Project

For a demo rack that needs to be stood up fast and moved between sites:

1. **GM is the practical choice.** Shorter lead time, lower cost, simpler logistics (120 V, any orientation).
2. **10,000 hr maintenance is fine** — this is a prototype/demo platform, not a 24/7 production system. Even at 10,000 hr you get > 1 year before first service.
3. **Pulse tube advantages (vibration, maintenance interval) don't materially help AQFP electrical testing.** If we were doing scanning probe microscopy or optical alignment, pulse tube would be worth the premium.
4. **The PT205 being a prototype with 36–40 week lead time eliminates it** from contention for the near-term build regardless.

Pulse tube should be reconsidered for a future permanent installation where unattended multi-year operation and low vibration are priorities.

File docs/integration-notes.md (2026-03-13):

# Integration Notes

Running notes on physical integration, site-specific considerations, and lessons learned during assembly.

## Vertiv Site

- Confirm available utilities: facility power (voltage, phase, amperage), cooling water, compressed air.
- Confirm floor space and rack placement constraints.
- Determine what Vertiv provides vs what we bring (rack, PDU, network, etc.).
- Shipping logistics for cryostat and compressor (heavy, fragile).

## CBA Site

- Existing lab infrastructure that can be reused (instruments, vacuum pumps, etc.).
- Relationship to garage lab cryostat build already in progress.
- Shared vs dedicated equipment policy.

## General Integration Notes

(Add notes here as the build progresses.)

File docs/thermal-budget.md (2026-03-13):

# Thermal Budget — RDK-101D + CNA-11RC

Last updated: 2026-03-11 (BOM rev 0.6)

## Cryocooler Capacity

RDK-101D with CNA-11RC compressor at 60 Hz (US power):

| Stage | Temperature | Capacity |
|---|---|---|
| 1st stage | 45–60 K | 3–5 W |
| 2nd stage | 4.2 K | **0.1 W (100 mW)** |

Note: headline spec (0.2 W) is with larger F-20L/FA-20L compressors.
CNA-11 footnote on SHI datasheet: 0.1 W @ 4.2 K. Use this for budgeting.

## Chamber Geometry (from BOM rev 0.6)

- Vacuum vessel: 6" OD SS tube (~140 mm ID)
- Radiation shield: ~Ø100 mm OD × 150–200 mm tall, 6061 Al
- Sample stage: ~Ø50 mm × 20 mm, OFHC Cu
- MLI: 10-layer aluminized mylar on radiation shield exterior

## 2nd Stage (4 K) Heat Budget

| Source | Parameters | Load (mW) |
|---|---|---|
| Radiation (40K → 4K) | ε≈0.1, A≈0.02 m², σ·(40⁴−4⁴) | 0.3 |
| DC wire conduction (40K → 4K) | 16× PhBr 36AWG, L=0.3m, k≈4 W/mK | 0.1 |
| RF coax conduction (40K → 4K) | 4× SS 0.086", L=0.3m, A_metal≈1.7e-6 m² | 2.0 |
| DUT dissipation | AQFP: nW–μW | ~0 |
| **Total** | | **~2.4** |
| **Available** | | **100** |
| **Utilization** | | **2.4%** |

Dominant load: RF coax conduction. Large margin.

## 1st Stage (40 K) Heat Budget

| Source | Parameters | Load (mW) |
|---|---|---|
| Radiation (300K → 40K) w/ 10-layer MLI | ~1.5 W/m², A≈0.08 m² | 120 |
| Radiation (300K → 40K) without MLI | ε≈0.05 bare, A≈0.08 m² | 1,800 |
| DC wire conduction (300K → 40K) | 16× PhBr 36AWG, L=0.5m, k≈25 W/mK | 3 |
| RF coax conduction (300K → 40K) | 4× SS 0.086", L=0.5m, k≈10 W/mK | 35 |
| **Total (with MLI)** | | **~160** |
| **Total (without MLI)** | | **~1,840** |
| **Available** | | **~3,000** |
| **Utilization (with MLI)** | | **5%** |
| **Utilization (without MLI)** | | **61%** |

MLI is not strictly required but reduces 1st stage load by >10×.
Without MLI the system still works but with reduced margin.

## Assumptions

- Wire lengths: ~0.5 m from 300K to 40K heat sink, ~0.3 m from 40K to 4K
- Phosphor bronze thermal conductivity: ~25 W/mK avg (300K–40K), ~4 W/mK avg (40K–4K)
- SS304 thermal conductivity: ~10 W/mK avg (300K–40K), ~2.5 W/mK avg (40K–4K)
- Emissivities: 0.05 (polished metal), 0.1 (unpolished/mixed surfaces at 4K)
- MLI performance: ~1.5 W/m² (typical for 10-layer at 300K–40K)
- 0.086" SS coax metal cross-section: ~1.7e-6 m² (outer + inner conductor)
- 36 AWG wire cross-section: 1.27e-8 m² per conductor
- AQFP DUT dissipation: negligible (nW–μW)

## Risk Items

1. **More RF cables**: each additional 0.086" SS coax adds ~0.5 mW at 4K
   and ~9 mW at 40K. Could add up to 10 cables before 4K budget reaches
   10% utilization.
2. **Larger DUT package**: if future DUT needs more wiring (e.g., 64-pin
   instead of 16), DC wire conduction roughly scales linearly.
   64 wires × 6 μW = 0.4 mW — still negligible.
3. **Wiring heat-sinking quality**: if 40K heat sink is poor (wires not
   well anchored), some 300K heat leaks directly to 4K. GE varnish and
   proper bobbin wrapping are essential.
4. **MLI installation quality**: crumpled or poorly layered MLI degrades
   performance significantly. If MLI is bad, radiation load approaches
   the "without MLI" case — still within budget but reduced margin.

## Conclusion

The RDK-101D + CNA-11RC is well-matched to this chamber. Both stages
have >90% margin with MLI. The small radiation shield area is the main
reason the budget works so comfortably. There is ample room to add more
wiring or a larger DUT in the future without upgrading the cryocooler.

---

## Appendix A: Radiation Shield Sizing — How Big Can We Go?

### Which stage constrains shield size?

**4K (2nd stage): not constrained by shield size.** For a small object
(sample stage) inside a larger enclosure (radiation shield), heat load
depends on the *object* area, not the enclosure area:
Q = ε_object × σ × A_object × (T_enclosure⁴ − T_object⁴).
Making the shield bigger does not increase the 4K heat load. The 2nd
stage budget is wire-conduction limited (~2 mW for 4 coax + 16 DC wires),
independent of shield geometry.

**40K (1st stage): this is the constraint.** Radiation from the 300K
vacuum vessel wall to the 40K shield scales directly with shield surface
area. Available budget: ~3 W (CNA-11RC, 60 Hz). Using 70% utilization
policy → 2.1 W, minus ~40 mW wires → ~2.06 W for radiation.

### Shield size vs. 1st stage heat load

| Shield (Ø × H) | Area (m²) | Vacuum vessel | With MLI | No MLI (ε=0.05) | No MLI (ε=0.15) |
|---|---|---|---|---|---|
| Ø100 × 150 mm | 0.063 | 6" CF nipple | 95 mW **(3%)** | 1.4 W (48%) | 4.3 W (OVER) |
| Ø150 × 200 mm | 0.129 | 8" CF nipple | 194 mW **(6%)** | 3.0 W (100%) | 8.9 W (OVER) |
| Ø200 × 300 mm | 0.251 | 10" CF nipple | 376 mW **(13%)** | 5.8 W (OVER) | 17 W (OVER) |
| Ø300 × 400 mm | 0.518 | 12–14" CF nipple | 777 mW **(26%)** | 12 W (OVER) | 36 W (OVER) |
| Ø400 × 500 mm | 0.942 | 16" CF nipple | 1.4 W **(47%)** | 22 W (OVER) | 65 W (OVER) |
| Max @ 70% util | ~1.4 m² | ~Ø350 × 1000 mm | 2.1 W **(70%)** | — | — |

### Rack fit check

19" rack: 482 mm panel width, ~450 mm between rails.

| Shield Ø | Vessel OD (approx) | Fits in rack? |
|---|---|---|
| 200 mm | ~250 mm (10") | **Yes** — 200 mm clearance |
| 300 mm | ~350 mm (14") | **Yes** — 130 mm clearance |
| 400 mm | ~450 mm (18") | Tight — needs careful layout |

### Takeaway

With MLI, shield size is **thermally unconstrained** for any rack-mount
design. A Ø200–300 mm shield (generous working space for multiple DUTs,
complex wiring, and magnetic shielding layers) uses only 13–26% of the
1st stage budget and fits comfortably in a 19" rack.

**Without MLI, shield size is tightly constrained.** Even a Ø150 × 200 mm
shield hits 100% utilization with polished surfaces. MLI is effectively
mandatory for any shield larger than the minimum baseline design.

The practical constraints on chamber size are:
1. Vacuum vessel cost and weight (bigger CF = heavier, pricier)
2. Cold head reach (2nd stage cold finger has a fixed length)
3. Rack depth and cryostat mounting logistics

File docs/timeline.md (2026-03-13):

# Project Timeline

**Target:** Operational cryo rack within 4 weeks of project start (by ~April 10, 2026).

## Week 1: Design Finalization & Procurement Start

- Finalize cryocooler selection (ADR required).
- Finalize cryostat approach: COTS vs custom, vendor selection.
- Send RFQs for all long-lead items.
- Complete thermal budget estimates for both stages.
- Order any items with known > 2 week lead times immediately.

## Week 2: Procurement & Fabrication

- Place orders for all major components.
- Design and order custom parts (DUT mount, adapter plates, wiring looms).
- Order magnetic shielding materials.
- Begin rack layout planning (physical arrangement, cable routing).

## Week 3: Assembly & Integration

- Receive and inspect major components.
- Assemble cryostat: cold head mounting, radiation shields, wiring.
- Install magnetic shielding.
- Wire feedthroughs and test at room temperature.
- Assemble rack: mount instruments, route cables, install PDU.

## Week 4: Cooldown & Commissioning

- Leak check vacuum system.
- Pump down and begin cooldown.
- Verify base temperature at both stages.
- Measure residual magnetic field at DUT location.
- Basic functional test with AQFP die (if available).
- Document as-built configuration.

## Critical Path Items

These are the items most likely to gate the schedule:

1. Cryostat / vacuum vessel (longest lead if custom; COTS may ship faster)
2. GM cryocooler cold head (typically 2-6 week lead)
3. Custom magnetic shielding (if non-stock dimensions)
4. Electrical feedthroughs (if high pin count or custom)

## Risk Mitigations

- Identify backup vendors for critical-path items.
- Consider used/refurbished cryocooler equipment to shorten lead time.
- Decouple phases: rack assembly and instrumentation setup can proceed in parallel with cryostat procurement.

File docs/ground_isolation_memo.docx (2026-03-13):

TECHNICAL MEMO

Adiabatic Machines, Inc.

Subject: | Ground Isolation Architecture for AQFP Latching JJ Output Amplifiers
Author: | Alex Wynn / Claude (Anthropic)
Date: | March 13, 2026
Status: | Working document — captures design discussion for future reference
References: | Ground return impedance simulation (shared Gnd, 1Ω coupling); SFQ5ee process design rules

# 1. Problem Statement

The current AQFP output amplifier design uses latching Josephson junction (JJ) amplifiers with differential outputs. On the fabricated test chip, 14 differential amplifiers share a common ground return path. Simulation confirmed that as little as 1 Ω of shared ground return impedance is sufficient to produce majority-vote artifacts, where the switching state of one amplifier influences the output of its neighbors through ground bounce.

The immediate fix identified was bonding more ground pads to reduce the shared impedance. However, this memo documents a more fundamental architectural solution: fully isolated ground domains for each output amplifier, with transformer-coupled inputs from the AQFP logic array.

# 2. System-Level Ground Architecture

## 2.1 Cryocooler Ground Path

In a standard SHI RDK-101D installation, the cold head cylinder is electrically continuous with the compressor chassis through the stainless steel body, the braided stainless flex lines, and the compressor housing. The compressor chassis is earth-grounded through its AC power cord. This means the second-stage cold finger, first-stage heat station, and warm flange are all galvanically connected to AC mains earth. The GM cycle valve motor produces periodic current transients at the cycle frequency (~1 Hz), and these transients propagate through the ground structure.

If the AQFP copper backplane at 4K is bolted directly to the second-stage cold finger, the circuit ground reference is defined in part by the compressor ground, injecting noise directly into the amplifier ground return problem.

## 2.2 Ceramic Electrical Isolation at the Cold Finger

The cold head body is galvanically connected to the compressor chassis through the stainless steel flex lines. There is no practical way to break this path at the warm end or in the flex lines without compromising helium integrity. Isolating the cold head from the vacuum jacket at the warm flange is also ineffective, since the cold head remains connected to the compressor through the hoses regardless. The only useful isolation point is between the second-stage cold finger and the copper backplane.

The solution is to insert an electrically insulating, thermally conductive ceramic disk at this interface. Single-crystal sapphire (Al₂O₃) is the traditional choice, with thermal conductivity of 100–1000 W/m·K at 4K depending on crystal quality. However, polycrystalline alumina is a more practical alternative for this application. Its thermal conductivity at 4K is lower (10–30 W/m·K) but still adequate, since the thermal boundary resistance at the indium foil interfaces dominates over the bulk resistance of the disk. Alumina disks are available off the shelf from CoorsTek, McMaster-Carr, and other suppliers for a few dollars, with lead times of days rather than weeks.

Recommended parameters: 25–30 mm diameter, 1–2 mm thick, polished both faces. Use indium foil (0.1 mm) on both interfaces and apply high clamping force. With indium foil interfaces, thermal boundary resistance is typically below 1 K/W for a 25 mm disk, resulting in a base temperature rise of a fraction of a kelvin depending on total heat load.

With the ceramic break in place, the circuit ground is defined entirely by the room-temperature measurement electronics, brought in through a dedicated ground conductor in the DC wiring harness. The cryostat body, cold head, and compressor are on a separate, isolated ground domain.

## 2.3 Prior Art

This approach is well established in the superconducting electronics and quantum computing communities. Sapphire heat-conducting elements are routinely used in cold-finger cryostats to provide thermal coupling while maintaining electrical isolation between the cold head and the sample stage (see, e.g., Woodcraft et al., "Thermal conductance of pressed metallic contacts augmented with indium foil or solder at sub-Kelvin temperatures"). The dilution refrigerator community uses sapphire breaks as standard practice when isolating millikelvin experiments from the fridge structure. For AQFP circuits operating at 4K (rather than 10–20 mK), the thermal requirements are much less stringent, and polycrystalline alumina is fully adequate.

## 2.3 Feedthrough Considerations

Standard CF-mounted hermetic multi-pin feedthroughs (e.g., Ceramaseal, Lesker) use ceramic-to-metal seals that are inherently electrically isolated from the flange body. This means individual pins do not short to the cryostat structure, preserving the isolation established by the sapphire disk. However, any coaxial or shielded lines where the shield connects to the flange must be checked carefully to avoid inadvertently re-grounding the backplane through the cryostat body.

Fiber feedthroughs are naturally isolated since glass is an insulator.

# 3. Per-Amplifier Ground Isolation

## 3.1 Concept

Each output amplifier is treated as a galvanically isolated module with its own private ground return. The input from the AQFP logic array is transformer-coupled (mutual inductance), which is natural for AQFP since the gates are already transformer-coupled by design. Each amplifier receives its own dedicated +V, –V, and GND wires running all the way back to the room-temperature electronics as a separate twisted triple.

In this architecture, the return current for amplifier N flows exclusively on amplifier N’s private GND wire. There is no shared impedance between amplifiers. The ground bounce coupling mechanism identified in simulation ceases to exist.

## 3.2 On-Chip Ground Plane Partitioning

If the on-chip ground plane (M0 in SFQ5ee) is left continuous under all amplifiers, bringing out separate ground wires does not fully solve the problem. The bias current would have two return paths: through the dedicated wire, and through the on-chip ground plane to a neighboring amplifier’s ground wire. Even though the ground plane is superconducting (zero DC resistance), it still has inductance, and at the switching frequencies of the latching JJs, inductive current division routes a fraction of the return current through the shared path. This shared path encloses magnetic flux, which can couple into nearby AQFP gates.

The solution is to split the on-chip ground plane into isolated islands, one per amplifier. Each amplifier gets its own ground pad connected only to its own local ground plane region, with no superconducting path to any other amplifier’s ground. The AQFP logic array retains its own continuous ground plane, since AQFP gates do not carry DC bias currents and do not suffer from the same ground bounce mechanism.

## 3.3 Layout Implementation

In SFQ5ee, the ground plane split is implemented as a gap in the M0 layer, typically a few microns wide, drawn around each amplifier cell. The critical layout constraint is the location of the gap relative to the input transformer.

The input transformer has a primary winding (AQFP side, ground return to the AQFP array ground plane) and a secondary winding (amplifier side, ground return to the amplifier’s isolated ground island). The ground plane gap runs between the primary and secondary ground returns. For a planar thin-film transformer with vertically stacked primary and secondary windings (typical in SFQ5ee), the ground plane gap underneath has minimal effect on the transformer coupling coefficient, since the magnetic flux is predominantly confined between the two winding layers rather than in the ground plane.

Care must be taken to ensure that the ground plane gap does not cross underneath any signal line or transformer winding, as this would force return currents to detour around the slot and alter inductance values. Since each amplifier is a self-contained cell with the input transformer at one end and output pads at the other, the gap can be routed cleanly around the cell boundary.

# 4. Wiring Budget

With 14 amplifiers and 3 wires each (+V, –V, GND), the output amplifier wiring requires 42 conductors. This is well within the capacity of standard 50-pin hermetic CF feedthroughs available from Ceramaseal and Lesker. Additional pins are needed for the AQFP array bias (AC clock lines) and any diagnostic or thermometry wiring.

Thermal load estimate for the amplifier wiring: 42 phosphor-bronze wires (36 AWG, ~100 mm length between first-stage thermalization anchor and 4K backplane) conduct approximately 10–20 μW per wire between 45K and 4K. Total conducted heat: ~0.4–0.8 mW. This is within the RDK-101D’s second-stage budget of 200 mW at 4.2K, though it represents a non-negligible fraction and must be accounted for in the overall thermal budget alongside structural supports, fiber conduction, and any other parasitic loads.

# 5. Cryostat Integration Notes

These notes pertain to the rackmount cryocooler system being developed in the CBA-Vertiv collaboration.

## 5.1 Vacuum Jacket

The cryostat is a standard DN200CF (10″ OD) tube. The RDK-101D cold head mates to one end via a Lesker zero-length reducer flange. The likely part numbers are RF1000X450 (DN200CF to DN63CF, if the cold head is CF4.50) or RF1000X600 (DN200CF to DN100CF, if CF6.00). Confirm the cold head flange size with SHI before ordering.

The opposite end of the tube receives a blank or multi-port DN200CF flange carrying the DC feedthrough(s), fiber feedthroughs, and pump-out port.

## 5.2 Thermal Design Summary

The RDK-101D provides 5 W at 45K (first stage) and 0.2 W at 4.2K (second stage) at 60 Hz. The 10″ bore creates significant radiative surface area at 300K. Multilayer insulation (10–20 layers of MLI) on the exterior of a copper or aluminum first-stage radiation shield is essential. All DC wires and fibers must be thermalized at the first-stage shield before passing to the 4K stage. Structural supports between first stage and second stage should be G10 or carbon fiber standoffs to minimize conductive load.

The copper backplane at 4K serves as the thermal mass, circuit ground plane, and mounting surface for the AQFP chip package. It connects to the second-stage cold finger through the alumina isolation disk described in Section 2.2.

## 5.3 Power Isolation Architecture

The RDK-101D paired with the CNA-11R rackmount air-cooled compressor draws only 1.3–1.5 kW on single-phase 120V. This is small enough that isolating the compressor behind a 1.5–2 kVA isolation transformer is technically feasible. However, a careful analysis of the three possible isolation configurations shows that isolating only the measurement electronics is the preferred approach.

### Option A: Single isolation transformer for everything

In this configuration, the compressor, cold head, and readout electronics all sit behind one isolation transformer, sharing a single isolated ground domain. This eliminates building mains noise and is simple to implement (one transformer, one plug). However, the compressor motor’s switching currents flow through the ground bus of the isolation transformer, and that same ground bus serves as the readout’s voltage reference. The compressor draws amps; the readout measures microvolts. Current flowing through the finite impedance of the shared ground conductor (even the ground bus bar inside the transformer) creates a voltage drop that the readout sees as noise. The alumina disk keeps motor currents out of the 4K backplane, but the room-temperature readout electronics still share a ground with the compressor. This configuration trades building mains noise for compressor motor noise on the measurement ground.

### Option B: Isolate only the readout (recommended)

The compressor stays on building mains, properly earth-grounded for safety and code compliance. The readout electronics (DAC/ADC, current sources for amplifier bias, clock generator) get their own small isolation transformer (500 W–1 kW is sufficient) with a clean, quiet, isolated ground reference. The alumina disk isolates the 4K backplane from the cold head/compressor structure. The only connection between the readout ground domain and the 4K circuit is the dedicated ground wires through the DC feedthrough pins.

In this architecture, there is no shared conductor carrying both motor current and signal return current at any point in the system. The compressor ground domain (earth/building mains) and the readout ground domain (isolated transformer secondary) are connected only through the interwinding capacitance of the isolation transformer, which a Faraday shield reduces to well under 100 pF. This is the standard instrumentation approach used in SQUID magnetometry and other sensitive superconducting measurements.

Suitable COTS units include the Tripp Lite IS500HG (500W, 120V, UL 60601-1, Faraday-shielded, ~$200–300) or the IS1000HG (1 kW) for systems with more readout hardware. These are compact enough for a 1U–2U rack shelf.

### Option C: Two separate isolation transformers

Compressor on one isolation transformer, readout on another. This provides maximum isolation from building mains for both subsystems, but introduces a ground loop risk. If the compressor’s isolated ground and the readout’s isolated ground are inadvertently connected through the cryostat body (compressor → flex lines → cold head → vacuum jacket → feedthrough shell → readout ground), a ground loop forms. The alumina disk breaks one leg of that loop at the cold finger, but if any feedthrough shield, cable braid, or scope probe ground touches the vacuum jacket, the loop is re-established. The area enclosed by this loop picks up 60 Hz and other stray magnetic fields from the lab environment, driving circulating currents that appear as noise. Two separate isolated ground domains with an accidental single-point connection is worse than a deliberate single-point ground design. This configuration is not recommended.

### Summary of ground domains

The recommended system architecture (Option B) has exactly two ground domains with a single, well-defined interface between them:

Domain 1 (earth ground): Building mains earth → compressor chassis → stainless flex lines → cold head body → cryostat vacuum jacket → rack chassis. This domain carries compressor motor currents and is referenced to building earth. No measurement signals exist in this domain.

Domain 2 (isolated measurement ground): Isolation transformer secondary → readout electronics ground bus → dedicated ground wires through DC feedthrough pins → copper backplane at 4K → AQFP circuit ground planes. This domain carries only signal and bias currents. It is isolated from Domain 1 by the alumina disk (at 4K) and by the ceramic seals in the hermetic feedthroughs (at 300K).

Critical discipline: no readout cable shield, coax braid, ground lug, or debug probe ground may touch the cryostat body, vacuum jacket, or rack chassis. Every electrical connection between the readout and the cryostat must pass through the feedthrough pins only, never through the flange housing. Standard insulated ceramic-to-metal hermetic feedthroughs maintain this isolation by design, but it can be defeated accidentally during assembly or debugging.

# 6. Product Architecture Summary

For a 19″ rackmount AQFP cryocooler product built around the RDK-101D and CNA-11R, the complete ground isolation architecture uses only COTS components with no custom fabrication required:

Rack power: CNA-11R compressor on dedicated 20A 120V mains circuit, earth-grounded. Readout electronics behind a 500W–1 kW medical-grade Faraday-shielded isolation transformer (e.g., Tripp Lite IS500HG or IS1000HG) on the same or separate mains circuit.

Cryostat: DN200CF tube, cold head mounted via Lesker RF1000X450 or RF1000X600 zero-length reducer. Multi-port DN200CF flange on opposite end with DC feedthrough(s), fiber feedthroughs, and pump-out.

Cold interface: Polycrystalline alumina disk (25–30 mm diameter, 1–2 mm thick, indium foil both sides) between second-stage cold finger and copper backplane. Breaks galvanic path between cryocooler structure (Domain 1) and circuit ground (Domain 2).

On-chip: Ground plane partitioned into isolated islands per output amplifier. Transformer-coupled inputs from AQFP array. Dedicated +V, –V, GND twisted triple per amplifier through multi-pin feedthrough.

This architecture addresses ground noise at three levels: building mains noise (isolation transformer), compressor motor noise (alumina disk), and inter-amplifier ground coupling (on-chip ground plane partitioning with per-amplifier wiring). All three use inexpensive, off-the-shelf components.

# 7. Open Questions

7.1 Chip-to-backplane interface: Wire bonds vs. spring fingers. Wire bonds are proven in the SCE world but create discrete, high-inductance ground contacts. Spring fingers (BeCu, gold-plated) can provide area-contact grounding across the chip backside, reducing ground path inductance. Spring fingers are also more compatible with swappable modules for a production system. Contact resistance at 4K needs characterization; gold plating on both surfaces is recommended.

7.2 Ground return wiring topology: The current plan is dedicated per-amplifier twisted triples through a multi-pin feedthrough. An alternative is a thick superconducting (NbTi) ground bus from the backplane to a high-current single-conductor feedthrough, but this adds thermal conduction load and complexity. The multi-pin approach with distributed ground pins (every 3rd–4th pin) is likely sufficient given the small switching energies of latching JJ amplifiers.

7.3 Backplane ground topology: Consider whether the copper backplane should be partitioned into quiet (amplifier) and noisy (clock distribution) zones with controlled interconnection (star ground), mirroring the on-chip ground plane partitioning. This prevents AC clock transients from coupling into the amplifier ground returns at the board level.

7.4 Confirm RDK-101D CF flange size: Believed to be CF4.50 / DN63CF based on the 130 mm body envelope, but the SHI datasheet with dimensional drawings is not publicly available. Confirm with SHI sales engineering before ordering the zero-length reducer.

7.5 Isolation transformer sizing: 500W is likely sufficient for the readout electronics alone. Verify total power draw of DAC/ADC boards, clock generator, bias current sources, and any rack-mounted amplifiers. Allow 20–30% headroom for inrush and future expansion. Medical-grade (UL 60601-1) units with Faraday shields are preferred for the low leakage current specification (<100 μA).

7.6 Debug access protocol: Establish a clear lab protocol that no scope probe ground, clip lead, or cable shield may be connected to the cryostat body or rack chassis during measurement. This is the most likely failure mode for the ground isolation architecture. Consider labeling feedthrough connectors and providing insulated BNC-to-feedthrough adapters as part of the system.

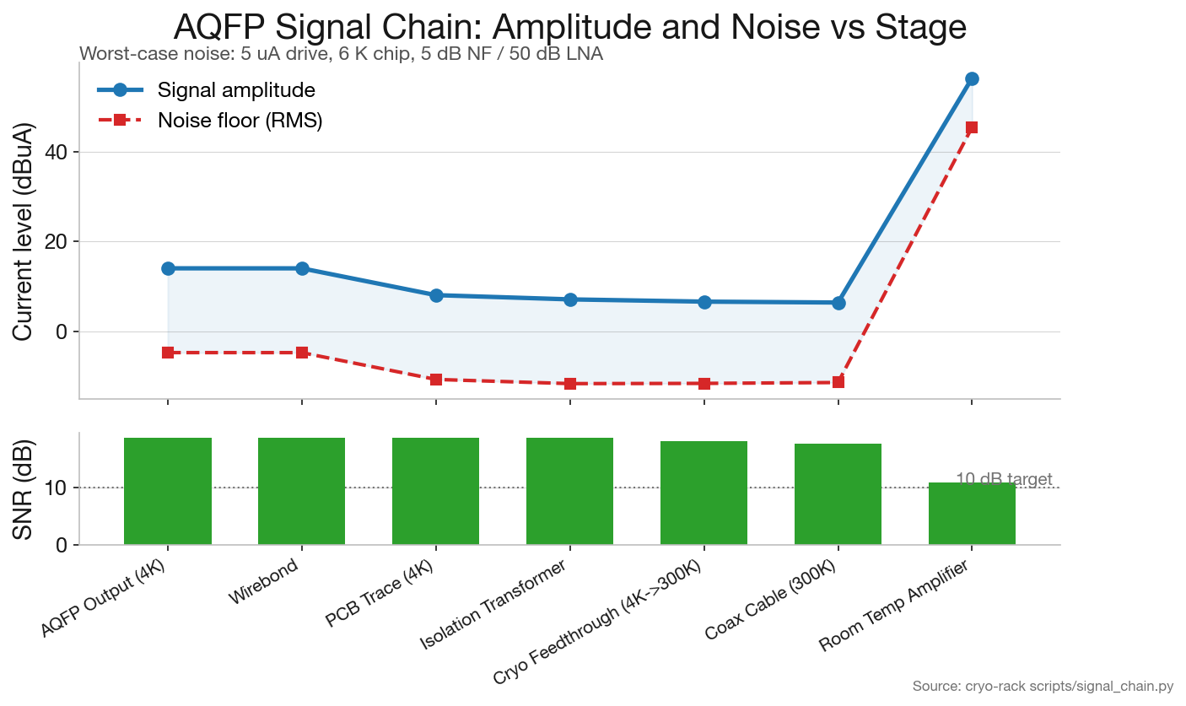
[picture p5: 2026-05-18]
docs/assets/signal_chain_waterfall_worst_noise.png

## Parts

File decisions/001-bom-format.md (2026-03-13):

# ADR-001: BOM Format and Tooling

**Date:** 2026-03-10
**Status:** accepted
**Deciders:** Alex Wynn

## Context

We need a bill of materials format that supports version control, diffing, scripted analysis, and eventual export to spreadsheet formats for procurement. The BOM must accommodate multiple deployment sites (CBA, Vertiv, future AM) with shared and site-specific items.

## Options Considered

1. **Google Sheets** -- Familiar, collaborative. Poor version control, hard to script against reliably, no good branching story.
2. **Excel in git** -- Binary diffs are useless. Merge conflicts are unresolvable.
3. **YAML in git with Python tooling** -- Human-readable, excellent diffs, scriptable, supports comments for rationale. Requires a small upfront investment in parsing scripts.

## Decision

YAML in a git repository, with Python scripts for summary, validation, and XLSX export. Site-specific overrides in separate YAML files that reference the master BOM.

## Consequences

Need to maintain the parsing scripts, but Claude Code can handle this with minimal friction. Procurement staff who need spreadsheets get them via the export script. All changes are tracked with full history.

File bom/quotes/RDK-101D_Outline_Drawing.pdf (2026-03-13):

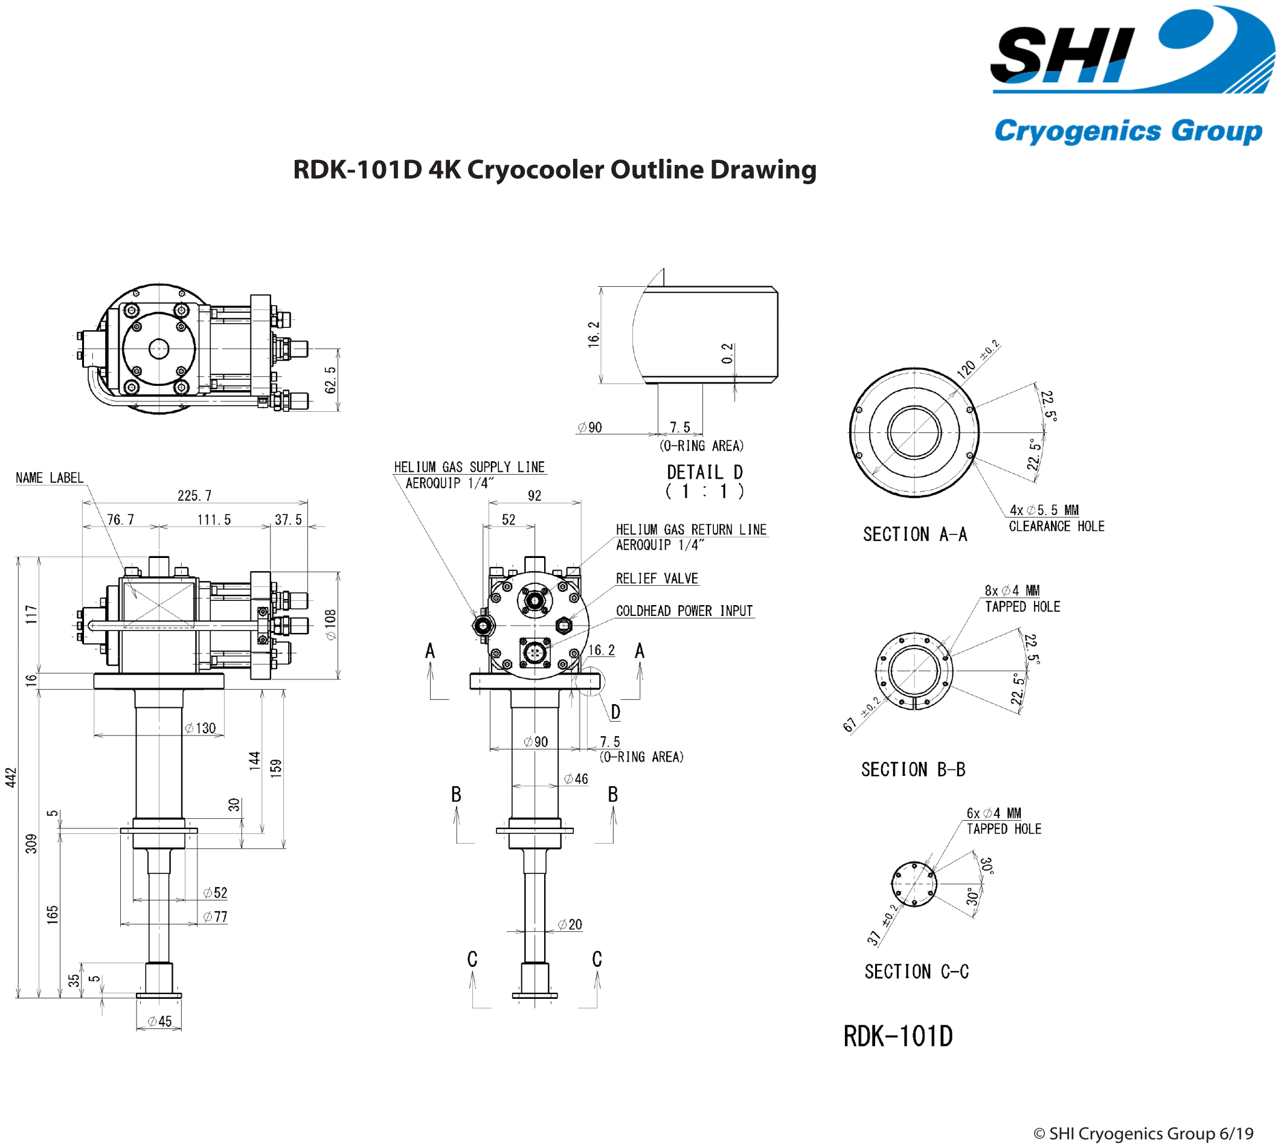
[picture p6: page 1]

RDK-101D4KCryocoolerOutlineDrawing

©SHICryogenicsGroup6/19

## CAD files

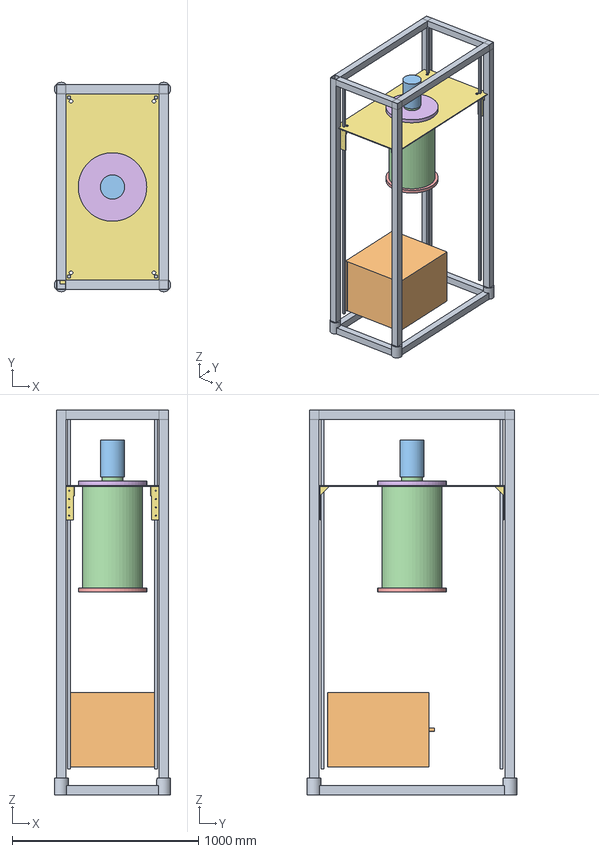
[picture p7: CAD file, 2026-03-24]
cad/assembly/cryostat-assembly.FCStd
625.0 x 1125.0 x 2066.9 mm
ServerRack
CNA11R_Compressor
ColdHead_Motor
ColdHead_CFFlange
ColdHead_Transition
ColdHead_1stStage
ColdHead_2ndTube
ColdHead_2ndTip
AluminaDisk
SampleVolume
RadiationShield
VacuumVessel_Body
VacuumVessel_BottomFlange
TopPlate
MountingFrame

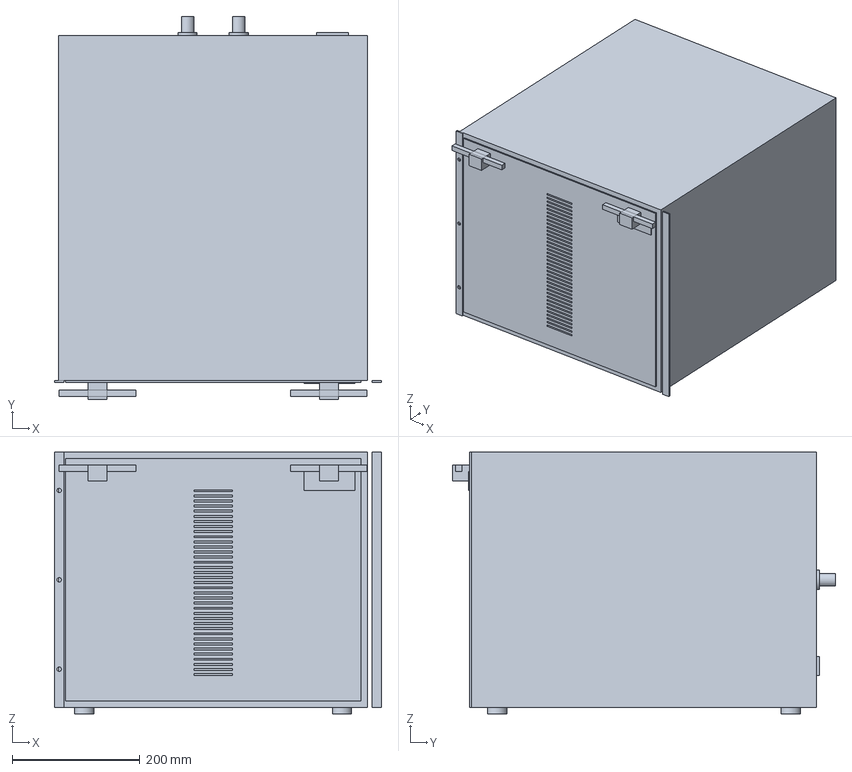
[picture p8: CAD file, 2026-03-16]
cad/parts/cna-11r-compressor.FCStd
512.6 x 600.0 x 410.0 mm

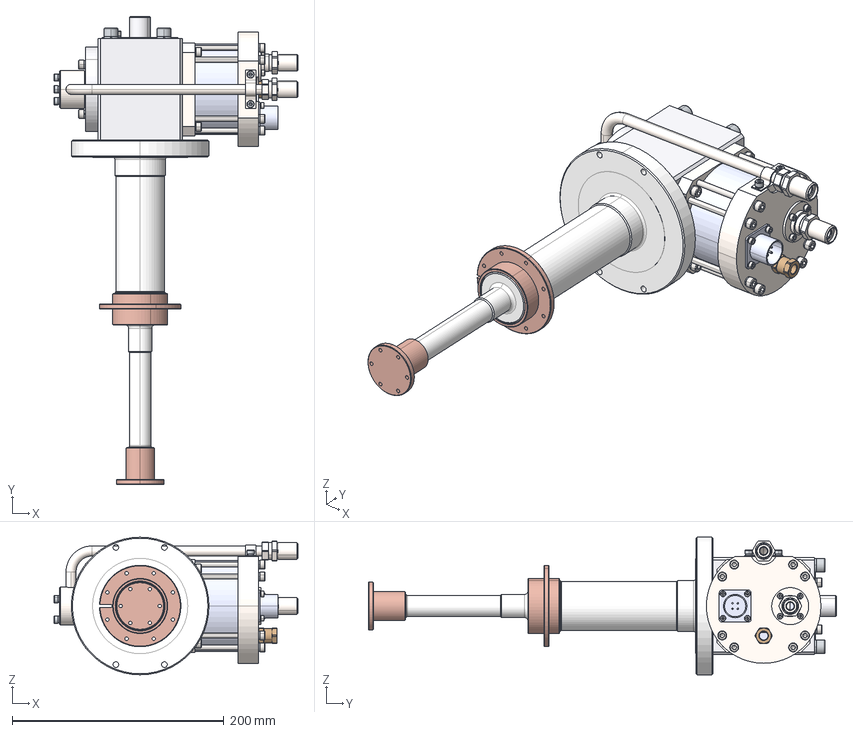
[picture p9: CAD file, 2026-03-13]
cad/reference/BMC401_cryocooler.stp
230.5 x 442.5 x 130.0 mm
SD02010239 O________ x 2
SD01055032 ____________ x 2
SD01021104 _________________M5*30 x 12
SD01042003 _______________5 x 20
SD01042005 _______________M8 x 4
SD01027004 _________________1 x 4
SD01042002 _______________4 x 5
SD01021002 _________________GB70.1-2008 M4__8 x 2
SD01011002 _________________M4*30 x 3
MA46020014 ____
SD02010581 ______
hexagon socket head cap screws gb_GB70.1-2000 M3X6 x 8
SD01042001 _______________3 x 8
MA46020202 ______________
SD02010493 __________ x 7
SD01027005 _______________70 x 8
MA46010001 ________
MA46010002 ________
MA46050003 ________
MA46050002 ________
MA46050001 ____
MA46020203 __________
MA46020201 ____________
MA46020104 ________
SD02010253 O________ _1
MA46020105 ________
SD01051048 O________
SD01051046 O________
SD01055095 __________
MA46020103 ____
MA46020102 ____
MA46020101 ____

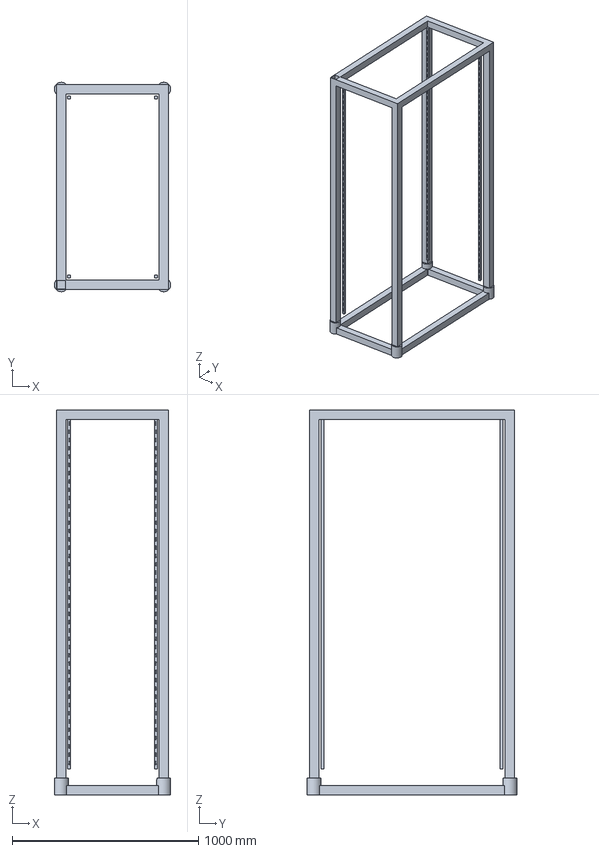
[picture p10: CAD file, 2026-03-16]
cad/parts/server-rack.FCStd
625.0 x 1125.0 x 2066.9 mm

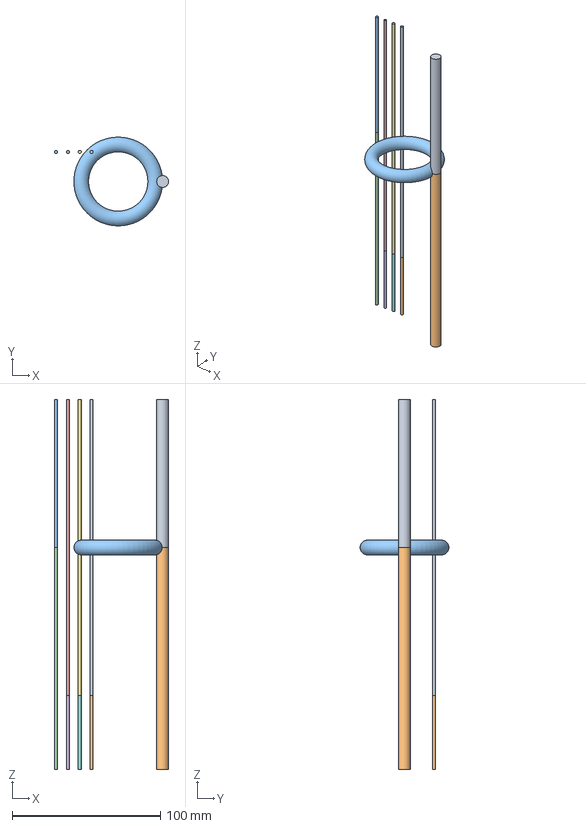
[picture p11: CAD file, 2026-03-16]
cad/parts/wiring.FCStd
77.1 x 60.0 x 250.0 mm
WireLoom_300K_40K
WireLoom_40K_4K
Coax1_300K_40K
Coax1_40K_4K
Coax2_300K_40K
Coax2_40K_4K
Coax3_300K_40K
Coax3_40K_4K
Coax4_300K_40K
Coax4_40K_4K
Heatsink_40K

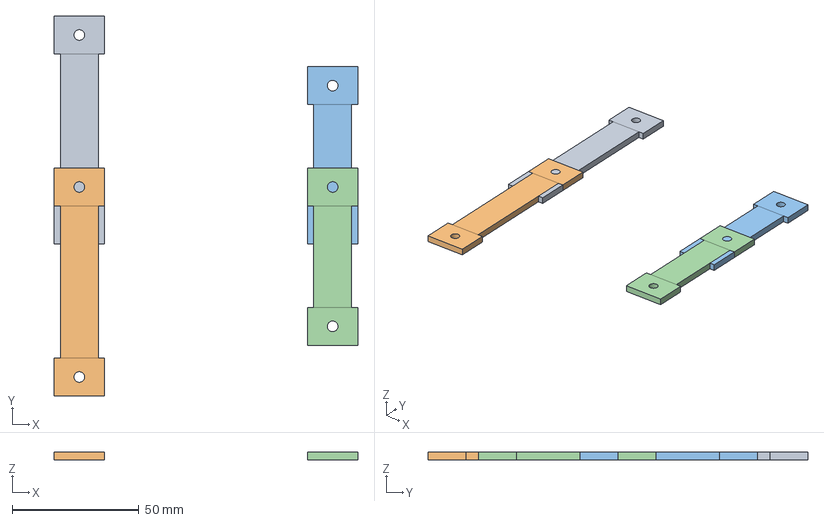
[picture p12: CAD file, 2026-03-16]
cad/parts/thermal-straps.FCStd
120.0 x 150.0 x 3.00 mm
Strap_1st_A
Strap_1st_B
Strap_2nd_A
Strap_2nd_B

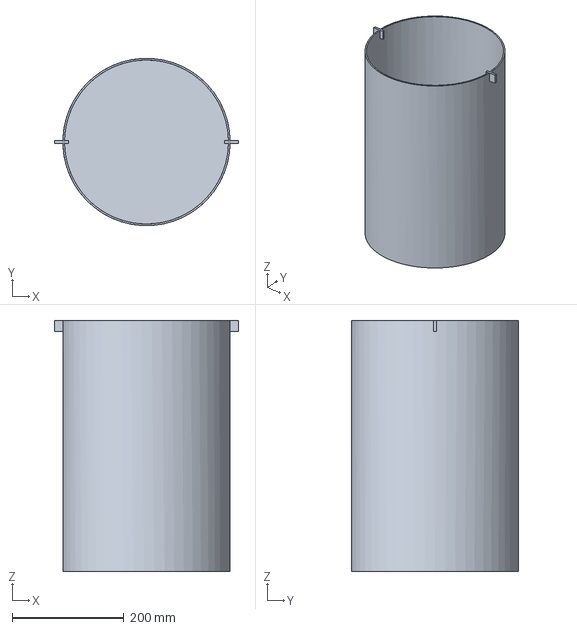
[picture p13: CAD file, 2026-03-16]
cad/parts/radiation-shield.FCStd
330.0 x 299.9 x 450.0 mm

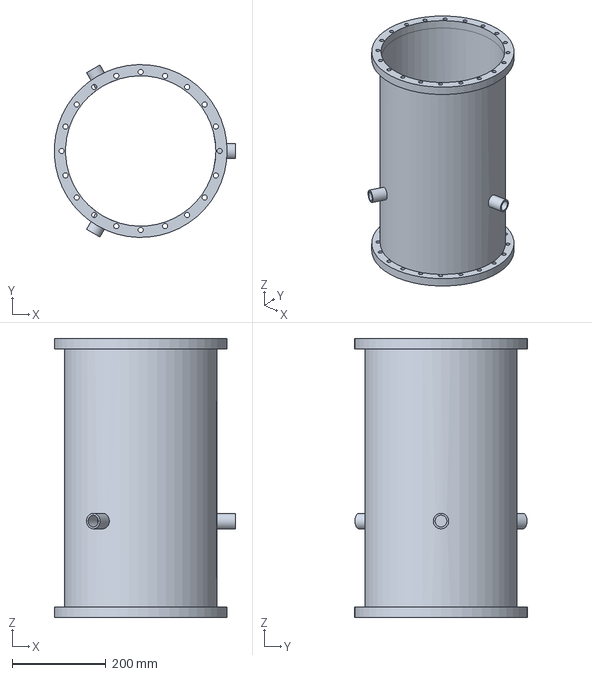
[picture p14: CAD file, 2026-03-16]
cad/parts/vacuum-vessel.FCStd
385.7 x 367.8 x 594.0 mm

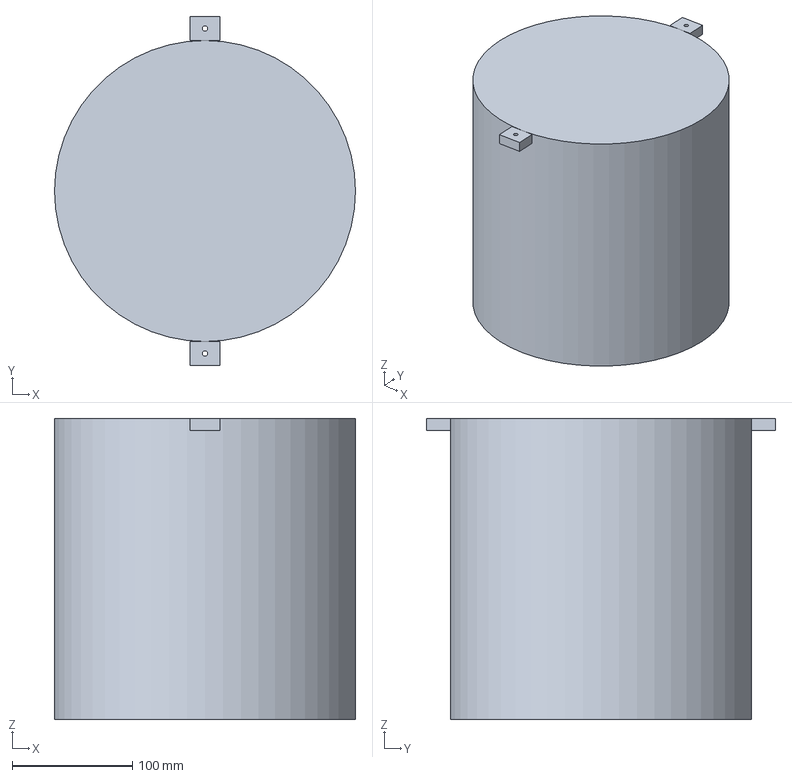
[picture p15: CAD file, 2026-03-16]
cad/parts/sample-stage.FCStd
250.0 x 290.0 x 250.0 mm

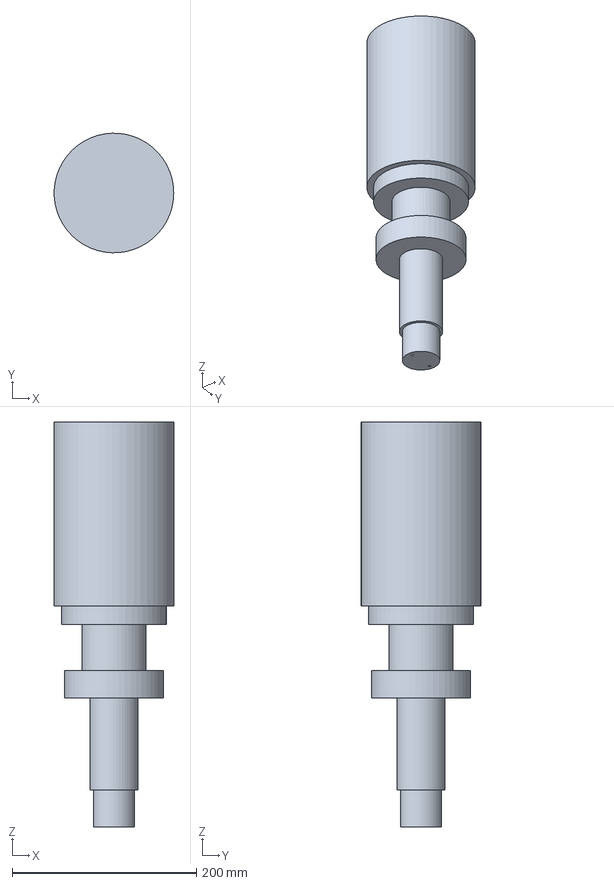
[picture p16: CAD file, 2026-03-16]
cad/parts/rdk-101d-cold-head.FCStd
129.9 x 129.9 x 440.0 mm

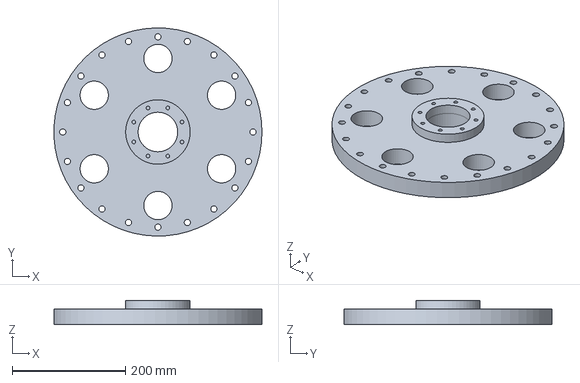
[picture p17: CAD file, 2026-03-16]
cad/parts/top-plate.FCStd
367.7 x 367.9 x 43.0 mm

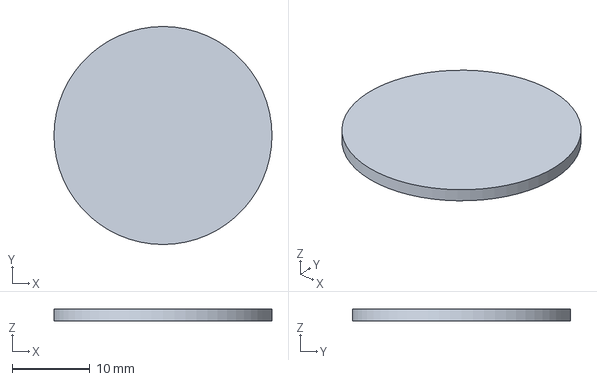
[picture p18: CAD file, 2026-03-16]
cad/parts/alumina-disk.FCStd
28.0 x 28.0 x 1.50 mm

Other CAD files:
cad/exports/cryostat-assembly.step

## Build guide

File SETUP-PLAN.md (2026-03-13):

# Cryo Rack Repo Setup Plan

Execute these steps in Claude Code to bootstrap the repository.

## Step 1: Create and initialize the repo

```bash
mkdir cryo-rack && cd cryo-rack
git init
```

If you want it on GitHub from the start:

```bash
gh repo create adiabatic-machines/cryo-rack --private --clone
cd cryo-rack
```

(Use `--private` since this will contain vendor pricing and system design details.)

## Step 2: Copy in the scaffold files

All the starter files are included alongside this plan. Copy the entire directory contents into your repo root. The structure is:

```
cryo-rack/
├── README.md
├── .gitignore
├── bom/
│   ├── bom.yaml              # Master BOM
│   ├── bom-cba.yaml          # CBA-specific overrides
│   ├── bom-vertiv.yaml       # Vertiv-specific overrides
│   └── vendors/              # Quote PDFs, correspondence
│       └── .gitkeep
├── decisions/
│   ├── template.md
│   ├── 001-bom-format.md
│   └── 002-cryocooler-selection.md
├── docs/
│   ├── system-architecture.md
│   ├── integration-notes.md
│   └── timeline.md
├── scripts/
│   ├── bom_summary.py
│   └── requirements.txt
└── specs/
    ├── thermal-budget.md
    └── requirements.md
```

## Step 3: Install script dependencies

```bash
pip install -r scripts/requirements.txt
```

## Step 4: Verify the BOM tooling works

```bash
python scripts/bom_summary.py bom/bom.yaml
```

This should parse the starter BOM and print a summary table with cost and status rollups.

## Step 5: Start filling in the BOM

The master `bom/bom.yaml` has placeholder entries organized by subsystem. Work through each assembly, filling in part numbers, vendors, costs, and lead times as you get quotes. Use Claude Code to help you add entries, run the summary script, and flag gaps.

## Step 6: Record decisions as you make them

When you choose a specific cryocooler, shielding approach, or wiring scheme, create a decision record in `decisions/` using the template. Even a few sentences is fine. The point is traceability.

## Day-to-day workflow with Claude Code

Typical commands you'll issue:

- "Add a line item to the cryocooler assembly for the compressor water chiller"
- "Run the BOM summary and show me what's still missing quotes"
- "Create a decision record for why we chose the RDK-101D over the PT410"
- "Export the BOM to xlsx for the Vertiv procurement team"
- "What's our total estimated heat load at the 4K stage?"
- "Show me all items with lead time over 3 weeks"

Claude Code can read the YAML, modify it, run the scripts, and generate new documents directly.

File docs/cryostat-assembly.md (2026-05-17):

# Cryostat Assembly — Exploded View (Text)

Last updated: 2026-03-11 (BOM rev 0.5)

## Overview

Top-loading design. Cold head hangs from top plate, cold end points down.
All vacuum hardware is standard CF/KF. Custom parts: radiation shield (Al)
and sample stage (Cu).

```
  ┌─────────────────────────────────┐
  │         COMPRESSOR              │  CNA-11RC, 120V, on floor / rack shelf
  │         (300 K)                 │
  └──────────┬──────────────────────┘
             │ flex lines (He supply + return)
             │ cold head cable (motor drive)
             │
  ═══════════╪══════════════════════════  ← TOP PLATE (300K)
  ║    ┌─────┴─────┐   FT  FT  FT  ║     8" CF multiport cluster flange
  ║    │ COLD HEAD │   ○   ○   ○   ║     FT = feedthrough ports (D-sub, SMA)
  ║    │  (motor)  │               ║     Center bore: CF seal to cold head
  ║    │           │               ║     Viton O-ring seal to vessel body
  ║    │           │               ║     (reusable for sample access cycling)
  ║    ├───────────┤ ← 1st stage   ║
  ║    │  (40 K)   │    flange     ║
  ║  ┌─┤           ├─┐             ║
  ║  │ └─────┬─────┘ │             ║
  ║  │  strap│  strap│             ║  ← OFHC Cu thermal straps (×2)
  ║  │       │       │             ║
  ║  │  ┌────┴────┐  │             ║
  ║  ├──┤ RAD     ├──┤  ·····      ║  ← RADIATION SHIELD (40K)
  ║  │  │ SHIELD  │  │  :MLI:      ║     6061 Al cylinder + end caps
  ║  │  │ (Al)    │  │  :   :      ║     FINEMET ribbon wrapped on surface
  ║  │  │         │  │  :   :      ║     MLI blankets on outside of shield
  ║  │  │ FINEMET │  │  :   :      ║     Wires heat-sunk here (GE varnish)
  ║  │  │ wrapped │  │  :   :      ║
  ║  │  │         │  │  :   :      ║
  ║  │  │  ┌───┐  │  │  :   :      ║
  ║  │  │  │2nd│  │  │  :   :      ║  ← 2nd STAGE (4K) cold finger
  ║  │  │  │stg│  │  │  :   :      ║
  ║  │  │  ├───┤  │  │  :   :      ║     Cu strap from 2nd stage ↓
  ║  │  │  │≈≈≈│  │  │  :   :      ║  ← ALUMINA DISK (electrical isolation)
  ║  │  │  │┌─┐│  │  │  :   :      ║  ← SAMPLE STAGE (4K)
  ║  │  │  ││P││  │  │  :   :      ║     OFHC Cu plate, gold-plated
  ║  │  │  ││b││  │  │  :   :      ║     Pb foil wrapped around DUT area
  ║  │  │  │├─┤│  │  │  :   :      ║     Cernox sensor mounted here
  ║  │  │  ││D││  │  │  :   :      ║  ← DUT PCB CARRIER
  ║  │  │  ││U││  │  │  :   :      ║     Wirebonded AQFP die
  ║  │  │  ││T││  │  │  :   :      ║     SMA connectors for RF
  ║  │  │  │└─┘│  │  │  :   :      ║
  ║  │  │  └───┘  │  │  :   :      ║
  ║  │  └─────────┘  │  :···:      ║
  ║  └───────────────┘             ║
  ║                                ║  ← VACUUM VESSEL BODY (300K)
  ║  ○ KF-25 (pump)               ║     SS CF nipple, 6" OD tube
  ║  ○ KF-25 (gauge)              ║     KF stubs welded on sides
  ║  ○ KF-25 (relief valve)       ║
  ║                                ║
  ═════════════════════════════════════  ← BOTTOM PLATE (300K)
                                          Blank 8" CF flange
       │              │
       │              │
  ┌────┴────┐    ┌────┴────┐
  │ HiCube  │    │ Pirani  │
  │ 80 Eco  │    │ gauge   │
  │ (pump)  │    │ CVM211  │
  └─────────┘    └─────────┘
```

## Assembly Layers (outside → inside, top → bottom)

### 300 K — Room Temperature

| # | Part | Material | Interface | BOM item |
|---|---|---|---|---|
| 1 | Equipment rack | Steel | Floor | rack-utilities |
| 2 | Compressor (CNA-11RC) | - | 120V wall outlet | cryocooler-system |
| 3 | Flex lines + cold head cable | SS/Cu | Compressor ↔ cold head | cryocooler-system |
| 4 | Vacuum vessel body | 304L SS | 8" CF top + bottom | cryostat-vessel |
| 5 | Top plate | 304L SS | 8" CF, center bore for cold head | cryostat-vessel |
| 6 | Bottom plate | 304L SS | 8" CF blank (part of nipple) | cryostat-vessel |
| 7 | Viton O-ring (top plate) | Viton | Sample access joint — reusable | rack-utilities |
| 7b | CF copper gaskets | OFHC Cu | Permanent joints (bottom, feedthroughs) | rack-utilities |
| 8 | KF side ports | SS | Welded on vessel body | cryostat-vessel |
| 9 | Pressure relief valve | - | KF-25 port on vessel | rack-utilities |
| 10 | Vacuum gauge (Pirani) | - | KF-25 port | vacuum-plumbing |
| 11 | HiCube turbo pump station | - | KF-25 bellows hose to vessel | vacuum-plumbing |
| 12 | D-sub feedthroughs (×2) | - | CF ports on top plate | vacuum-plumbing |
| 13 | SMA feedthroughs (×4) | - | CF ports on top plate | vacuum-plumbing |

### 300 K → 40 K — Transition

| # | Part | Material | Interface | BOM item |
|---|---|---|---|---|
| 14 | Cold head (RDK-101D) | - | CF seal through top plate | cryocooler-system |
| 15 | PhBr DC wiring loom | Phosphor bronze | Feedthrough → heat sink at 40K → 4K | thermal-wiring |
| 16 | SS coax cables (×4) | Stainless steel | SMA feedthrough → heat sink at 40K → 4K | thermal-wiring |
| 17 | MLI blankets | Al mylar + dacron | Wrapped around rad shield exterior | thermal-wiring |

### 40 K — First Stage

| # | Part | Material | Interface | BOM item |
|---|---|---|---|---|
| 18 | Thermal straps (×2) | OFHC Cu braid | 1st stage flange → rad shield | thermal-wiring |
| 19 | Indium wire | In | Crushed at bolted joints | rack-utilities |
| 20 | Radiation shield | 6061-T6 Al | Cylinder + end caps | cryostat-vessel |
| 21 | FINEMET ribbon | Nanocrystalline | Wrapped on rad shield surface | magnetic-shielding |
| 22 | Si diode sensor | - | Mounted on 1st stage or shield | temperature-monitoring |
| 23 | Wire heat sinking | GE varnish / Cu bobbins | Wires anchored to rad shield | rack-utilities |

### 4 K — Second Stage

| # | Part | Material | Interface | BOM item |
|---|---|---|---|---|
| 24 | Thermal straps (×2) | OFHC Cu braid | 2nd stage → sample stage | thermal-wiring |
| 25 | Indium wire | In | Crushed at bolted joints | (same as #19) |
| 25b | Alumina isolation disk | Al₂O₃ (polycrystalline) | Between cold finger and sample stage | cryostat-vessel |
| 26 | Sample stage | OFHC Cu | Clamped to cold finger through alumina disk | cryostat-vessel |
| 27 | Lead foil shield | Pb, 0.1 mm | Wrapped around DUT area | magnetic-shielding |
| 28 | Cernox sensors (×2) | - | 1 on 2nd stage, 1 on DUT mount | temperature-monitoring |
| 29 | DUT PCB carrier | FR4/Rogers + Cu | Bolted to sample stage | thermal-wiring |

## Signal Path

```
External instruments (GS200, 2182A)
       │ DC: BNC/banana cables
       │ RF: SMA cables
       ▼
  ┌─────────────┐
  │ Feedthroughs │  D-sub (DC), SMA (RF) — hermetic, on top plate
  └──────┬──────┘
         │ PhBr wire (DC), SS coax (RF) — inside vacuum
         │
    ┌────┴────┐
    │ 40K     │  Wires thermally anchored (GE varnish / Cu bobbins)
    │ shield  │  Intercepted heat goes to 1st stage
    └────┬────┘
         │
    ┌────┴────┐
    │ 4K DUT  │  DC bias pads + SMA edge-launch on PCB
    │ carrier │  Wirebonded to AQFP die
    └─────────┘
```

## Temperature Readout Path

```
  Cryocon 22C controller (rack-mounted, 300K)
       │ 4-wire sensor cables through D-sub feedthrough
       │
       ├── Cernox #1: on 2nd stage cold finger (4K reference)
       ├── Cernox #2: on DUT mount / sample stage (4K at DUT)
       └── Si diode: on 1st stage or rad shield (40K)
```

## Vacuum Path

```
  Atmosphere
       │
  ┌────┴────┐
  │ HiCube  │  Turbo + diaphragm backing pump
  │ 80 Eco  │  KF-25 bellows hose to vessel
  └────┬────┘
       │
  ┌────┴────┐
  │ Vessel  │  SS CF nipple body
  │ interior│  Pirani gauge on KF-25 side port
  │         │  Relief valve on KF-25 side port
  └─────────┘
       ↓ at 4K, cryopumping maintains <1e-6 Torr
```

## MLI (Multi-Layer Insulation) — Sourcing & Installation

**Required for shields larger than Ø150mm.** See thermal budget appendix.
For Ø200–300mm shields, MLI reduces 1st stage radiation load by >10×.

### Material needed

10 layers on a Ø200mm × 300mm shield: ~2 m² each of reflector + spacer.

### Sourcing options

| Option | Reflector | Spacer | Cost | Lead |
|---|---|---|---|---|
| **DIY (recommended)** | Aluminized mylar photo-film (Amazon) | 100% polyester mosquito netting ([Joann Fabric](https://www.joann.com)) | ~$50-75 | Days |
| **Professional** | Double-aluminized PET ([Dunmore](https://www.dunmore.com), Bristol PA) | Dacron netting (cryo supplier) | ~$300-500 | 1-2 wk |
| **Pre-made blankets** | Custom MLI blankets ([FrakoTerm](https://frakoterm.com), Poland) | Integrated | ~$500+ | 2-4 wk |

WSU HYPER lab [tested DIY vs professional MLI](https://hydrogen.wsu.edu/2020/06/16/how-to-make-cryogenic-multi-layer-insulation-mli-shields/)
and found comparable thermal performance after a few layers.
With our >90% thermal margin, DIY is more than adequate.

### Installation notes

- Wear gloves (fingerprint oils reduce reflectivity)
- Stagger seams between layers (avoid thermal short circuits)
- Leave small gaps in seams for pump-out (don't fully tape-seal)
- Use mylar tape on seams, not metal fasteners
- Anchor with pipe cleaners or wire ties (minimal thermal conduction)
- FINEMET goes on the radiation shield surface; MLI wraps over FINEMET
- Adds ~15-30 min to pumpdown time (outgassing from extra surface area)

## 3D Printed Parts (PLA at 4K)

PLA has been validated at 4K for non-thermally-conductive structural parts.
Low thermal conductivity is a feature for isolation. Fast iteration, cheap.

### Print candidates

| Part | Benefit | Notes |
|---|---|---|
| Wire routing bobbins (40K) | Custom geometry for PhBr + coax routing | Replaces machined Cu bobbins |
| DUT mount adapter | Iterate with DUT pinout changes | Sits on Cu sample stage |
| Magnetic shield brackets | Hold FINEMET + Pb foil in position | Inside radiation shield |
| Thermal isolation standoffs | Low-k spacers between stages | Replaces G10 tubes |
| Feedthrough strain reliefs | Cable management from top plate to shield | Replaces zip ties / Kapton |
| Assembly alignment jigs | Temporary fixtures during integration | Don't need to survive cryo |

### Must remain metal

| Part | Reason |
|---|---|
| Radiation shield | Must conduct heat to 1st stage (Al) |
| Sample stage | Must conduct heat to 2nd stage (Cu) |
| Vacuum vessel + top plate | Must hold vacuum (SS) |
| Thermal straps | Must conduct heat (OFHC Cu) |

### Outgassing

PLA outgasses water + volatiles at room temp in vacuum. Manageable:
turbo pump handles it during pumpdown (adds a few minutes). Once cold,
outgassing drops to near zero. Optional: light bake at 50–60°C under
vacuum before cooldown drives off most volatiles. Do not exceed 60°C
(PLA glass transition).

## Ground Isolation

See ADR-004 (`docs/decisions/004-ground-isolation.md`) and `docs/ground_isolation_memo.docx`.

The cold head body is galvanically continuous with the compressor chassis
(through stainless flex lines) and therefore to AC mains earth. The GM
valve motor injects periodic current transients into this ground structure.

**Two isolation points** keep motor noise out of the measurement path:

1. **Alumina disk at 4 K** — polycrystalline Al₂O₃, 25–30 mm diameter,
   1–2 mm thick, indium foil both faces. Inserted between the 2nd-stage
   cold finger and the copper backplane. Breaks the galvanic path between
   the cryocooler structure and the circuit ground.

2. **Isolation transformer at 300 K** — Tripp Lite IS500HG (500 W,
   Faraday-shielded, medical-grade). Powers only the readout electronics.
   Compressor stays on building mains, earth-grounded.

This creates two ground domains:

- **Domain 1 (earth):** mains → compressor → flex lines → cold head →
  vacuum jacket → rack chassis. No measurement signals.
- **Domain 2 (isolated):** isolation transformer → readout electronics →
  feedthrough pins → copper backplane at 4 K. Signal and bias only.

**Assembly discipline:** no readout cable shield, coax braid, or probe
ground may touch the cryostat body or rack chassis. All electrical
connections between readout and cryostat pass through feedthrough pins
only. Ceramic-to-metal hermetic feedthroughs maintain isolation by design.

## Open Design Questions

1. **Vessel length**: depends on RDK-101D dimensions from outline drawing.
   Need: 1st stage to 2nd stage distance + sample space below 2nd stage
   + clearance above 1st stage for MLI/wiring routing.
2. **Top plate port layout**: number and placement of CF sub-ports depends
   on total wire count and whether pumping goes on side or through top.
3. **Radiation shield height**: must clear 2nd stage + sample stage + DUT
   + Pb foil + wiring strain relief. Target ≥120 mm internal height.
4. **FINEMET inside or outside MLI?**: FINEMET on the radiation shield
   surface (at 40K), MLI on outside of FINEMET. FINEMET must be at
   cryogenic temp for best permeability.
5. **Vessel bore size**: current design uses DN160CF (6" OD tube, 8" CF
   flanges, ~140 mm ID). Ground isolation memo describes DN200CF (8" OD
   tube, 10" CF flanges, ~200 mm ID) with a Lesker zero-length reducer
   (RF1000X450 or RF1000X600) for cold head mounting. Larger bore gives
   more space for wiring and radiation shield but increases radiative
   load (MLI mandatory). Resolve before ordering vessel.
6. **RDK-101D CF flange size**: believed CF4.50 / DN63CF based on
   130 mm body envelope. Confirm with SHI before ordering zero-length
   reducer.

---

## Working Render

FreeCAD model of the complete rack-mounted system:

Rack Assembly

*42U rack with cryostat mounted at U35 (top) and CNA-11R compressor at U1 (bottom).
Aluminum mounting frame supports cryostat flange on 19" rails.*

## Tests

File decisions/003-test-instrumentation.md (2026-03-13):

# ADR-003: Test Instrumentation Selection

**Status:** accepted  
**Date:** 2026-03-10  
**Deciders:** Team

## Context

The cryo rack needs DC bias sourcing and voltage readout for AQFP superconducting circuit characterization. Superconducting circuits are extremely sensitive to electromagnetic interference — standard bench supplies (Rigol, Keysight bench PSUs) and general-purpose SMUs (Keithley 2400 series) are too noisy. Instrument selection must reflect what the SC electronics community actually uses.

Phase 1 is basic IV characterization and functional bring-up. Phase 2 is low-speed digital functional testing (1 kHz – 1 MHz pattern generation and capture).

## Phase 1: Characterization

### Minimum Viable — Yokogawa GS200 + Keithley 2182A

- **GS200** (~$4k): Low-noise DC source, ±32 V / ±200 mA, 100 µVp-p noise. Industry standard across quantum/SC labs for Josephson junction biasing.
- **2182A** (~$6.7k): Dual-channel nanovoltmeter, 1 nV sensitivity, 15 nV p-p noise at 1s. The standard readout for SC voltage measurements.
- Together they cover single-channel IV curves and basic characterization.

### Budget Alternative — GS200 + Keithley DMM6500

- **DMM6500** (~$1.9k): 6.5-digit DMM, 100 nV sensitivity. Can replace the 2182A for initial bring-up and functional checks.
- Tradeoffs: 10x worse noise floor, no delta-mode. Fine for "does the chip respond?" testing.
- Upgrade path to 2182A is clean when precision matters.

### Not Suitable

- **Keithley 2400 series** — too noisy for SC circuits.
- **Rigol / Keysight bench supplies** — not low-noise sources; only suitable for non-SC power delivery.
- **Keithley 6221** — purpose-built AC/DC precision current source, pairs with 2182A for delta-mode. Standard at Hypres/NIST. Not selected because team doesn't use them and GS200 covers the need.

## Phase 2: Digital Functional Testing

Low-speed digital testing of AQFP circuits requires multi-channel stimulus (pattern generation at kHz–MHz rates) and synchronized readout (pattern capture and analysis).

### Option A: OCTOPUX (RedHiTech)

- **Stimulus:** Multi-channel digital pattern generation, up to 1 MHz
- **Readout:** 2 MS/s multi-channel ADC, 0.5 µV differential accuracy, pattern analysis
- **Channels:** 32 / 64 / 128 universal I/O
- **Ecosystem:** MATLAB-based, automated measurement scripts
- **Strengths:** Purpose-built for SC circuit testing since 1997. Used at Hypres and NIST. Complete test loop — generate, acquire, analyze. The only COTS system designed specifically for RSFQ/AQFP digital testing.
- **Weaknesses:** Niche product, likely long lead time. Pricing unknown (contact RedHiTech).
- **URL:** https://www.redhitech.com/octopux.html

### Option B: QDAC-II (Quantum Machines / QDevil)

- **Stimulus:** 24-channel AWG, 1 MS/s per channel, up to 300 kHz (filter limited). DC + sine + triangle + square + arbitrary waveforms. Ultra-low noise (<10 nV/√Hz), 25-bit DC resolution.
- **Readout:** DC current sensors only (pA-level per channel). **No ADC** — cannot capture circuit output at speed. Needs external digitizer to close the test loop.
- **Channels:** 24
- **Ecosystem:** Python/QCoDeS, integrates with Quantum Machines OPX
- **Strengths:** Excellent multi-channel low-noise stimulus. Good for bias + low-speed waveform generation. 1U compact form factor.
- **Weaknesses:** Output only — no acquisition path. 300 kHz bandwidth limit. ~$18-21k for stimulus alone; still need a digitizer (~$2-5k) for readout.
- **URL:** https://quantum-machines.co/products/qdac
- **Quote:** https://www.quantum-machines.co/request-a-quote-qdac/

### Option C: Custom FPGA / Red Pitaya

- Low-cost digitizer + DAC approach. Red Pitaya STEMlab 125-14 is ~$500 with 2-ch 125 MS/s ADC + 2-ch 14-bit DAC. Could pair with QDAC-II for stimulus.
- Requires custom firmware/software development.
- Most flexibility, lowest cost, highest effort.

## Decision

**Phase 1:** GS200 + 2182A as the minimum viable test pair. DMM6500 available as budget readout alternative (replaces 2182A, saves ~$4.8k).

**Phase 2:** Evaluate OCTOPUX and QDAC-II + digitizer once Phase 1 characterization is complete and digital testing requirements are defined. OCTOPUX is the stronger option if available; QDAC-II is a good stimulus box if paired with a separate ADC.

## Consequences

- Phase 1 instruments (GS200, 2182A) are single-channel. Scaling to multi-channel bias requires a Phase 2 investment.
- The clock signal generator line item in the BOM (for GHz AQFP clocking) is separate from the kHz–MHz digital test stimulus discussed here.
- OCTOPUX pricing and lead time need to be confirmed with RedHiTech before Phase 2 planning.

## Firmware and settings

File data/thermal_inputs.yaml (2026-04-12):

# Thermal Budget Inputs for Cryo-Rack Demo System
#
# All inputs parameterized here -- no hardcoded numbers in thermal_budget.py.
# Reference: docs/thermal-budget.md, decisions/002-cryocooler-selection.md
#
# Thermal conductivity integrals are cumulative from 0 K to T (units: W/m).
# To get the integral from T_cold to T_hot:
#   integral = table[T_hot] - table[T_cold]
# Source: NIST Cryogenic Materials Database, Woodcraft (2005), Ekin (2006).
#
# Convention: all lengths in meters, areas in m^2, temperatures in kelvin,
# thermal conductivities in W/(m*K), conductivity integrals in W/m.

# --- Cryocooler capacity ---
cryocooler:
  model: "Sumitomo RDK-101D + CNA-11RC"
  stages:
    - name: "1st stage"
      temperature_k: 45.0
      capacity_w: 3.0        # ~3 W at 45 K with CNA-11RC at 60 Hz
    - name: "2nd stage"
      temperature_k: 4.2
      capacity_w: 0.1        # 100 mW at 4.2 K (CNA-11RC footnote)

# --- Thermal stages ---
# Heat loads are computed for two intervals:
#   300 K -> 1st stage (45 K)
#   1st stage (45 K) -> 2nd stage (4.2 K)
temperatures:
  room: 300.0
  first_stage: 45.0
  second_stage: 4.2

# --- Material thermal conductivity integrals (0 K to T), W/m ---
# Q_conduction = (A / L) * (integral[T_hot] - integral[T_cold])
#
# These are polynomial or tabulated integrals of k(T) from 0 to T.
# Values below are representative for the temperature points we need.
materials:
  phosphor_bronze:
    description: "Phosphor bronze (CuSn8, C52100), 36 AWG DC wiring"
    # Thermal conductivity integral from 0 K to T (W/m)
    # Source: NIST/Woodcraft. PhBr has k ~ 48 W/(m*K) at 300K, ~19 at 40K, ~0.5 at 4K
    conductivity_integral:
      4: 1.0           # 0->4 K
      45: 470.0        # 0->45 K
      300: 6200.0      # 0->300 K

  ss304:
    description: "Stainless steel 304, coax outer/inner conductors and mech supports"
    # k ~ 15 W/(m*K) at 300K, ~8 at 40K, ~0.3 at 4K
    # Integral 4->300 K ~ 3060 W/m (matches ~1.6 W*cm/cm^2 = 160 W*cm/m^2
    #   converting: 3060 W/m ~ 30.6 W*cm/cm^2? No:
    #   Literature: SS304 integral 4K->300K = ~30 W*cm/cm (= 3000 W*m/m^2 = 3000 W/m)
    #   Or equivalently 1.6 W*cm/cm^2 means per unit (A/L) in cgs.
    #   Let's be precise: the thermal conductivity integral
    #     integral from 4K to 300K of k(T) dT ~ 3000 W/m for SS304.
    conductivity_integral:
      4: 0.5           # 0->4 K
      45: 185.0        # 0->45 K
      300: 3000.0      # 0->300 K

  ofhc_copper:
    description: "OFHC copper (RRR~100), thermal straps and sample stage"
    # k ~ 400 W/(m*K) at 300K, much higher at low T, peaks ~20 K
    conductivity_integral:
      4: 600.0         # 0->4 K
      45: 15000.0      # 0->45 K
      300: 120000.0    # 0->300 K

  g10_fiberglass:
    description: "G10/FR4 fiberglass composite, cryogenic mechanical supports"
    # G10 (NEMA grade) is the standard low-conductivity structural material for
    # cryogenic support standoffs.  Much lower thermal conductivity than SS304:
    #   k ~ 0.7 W/(m*K) at 300K, ~0.25 at 40K, ~0.05 at 4K (normal to cloth)
    # Source: NIST Cryogenic Materials Database; Woodcraft & Sherrill (2004);
    #   Ekin (2006) "Experimental Techniques for Low-Temperature Measurements"
    # Note: values are for heat flow NORMAL to the glass-cloth layers.
    # Parallel-to-cloth conductivity is ~2x higher.
    # Alternative for non-load-bearing parts: PLA or PLA wrapped in fiberglass
    # (even lower conductivity, but limited structural strength).
    conductivity_integral:
      4: 0.04          # 0->4 K
      45: 5.5           # 0->45 K
      300: 153.0         # 0->300 K  (~10x lower than SS304's ~3000 W/m)

  alumina:
    description: "Alumina (Al2O3 99.5% polycrystalline), ground isolation disk"
    # Polycrystalline alumina (NOT single-crystal sapphire):
    # k ~ 30 W/(m*K) at 300K, peaks ~50 W/(m*K) near 30-40K, drops sharply below 10K
    # Source: Woodcraft (2005), Touloukian Vol 2
    conductivity_integral:
      4: 2.0           # 0->4 K (very low; k ~ 0.5 W/(m*K) at 4K)
      45: 500.0        # 0->45 K
      300: 8000.0      # 0->300 K

# --- Wiring: DC bias lines ---
dc_wiring:
  description: "Phosphor bronze 36 AWG twisted pairs, heat-sunk at 40K"
  material: phosphor_bronze
  count: 16                     # number of individual conductors
  wire_cross_section_m2: 1.27e-8  # 36 AWG = 0.0127 mm^2
  # Two segments: 300K->45K and 45K->4.2K
  segments:
    - name: "300K to 1st stage"
      t_hot_k: 300.0
      t_cold_k: 45.0
      length_m: 0.5
    - name: "1st stage to 2nd stage"
      t_hot_k: 45.0
      t_cold_k: 4.2
      length_m: 0.3
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

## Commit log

2026-03-13 Initial commit: cryo rack design package
    - BOM with cryocooler options (RDK-101D, RDC-02K, BMC401, PT205)
    - Cryostat assembly docs with ground isolation (alumina disk, Option B)
    - ADR-004: ground isolation architecture
    - Design package for Vertiv deployment
    - Ground isolation memo integrated
    Made-with: Cursor
    [BMC401_cryocooler.stp]
2026-03-13 Fix mermaid diagram and add concept render image
    - Fix flowchart node ordering so subgraph nodes are defined before referenced
    - Add cryo rack concept render to Executive Summary
    - Regenerate PDF
2026-03-13 Update compressor to rack-mounted configuration
    - Remove floor-standing compressor references
    - CNA-11RC fits standard 19-inch rack
2026-03-13 Update system diagram: serial thermal stages + isolation transformer
    - 2nd stage now shown below 1st stage (coldHead → radShield → sampleStage)
    - Add isolation transformer (IS500HG) for test & computing interfaces
    - Rename test equipment to generic "Test & Computing Interfaces"
2026-03-13 Show top plate with feedthroughs in system diagram
    All cables and cold head mount route through the top plate.
2026-03-13 Restructure diagram: cold head and feedthroughs on top, Al vessel
    - Cold head sits on top of cryostat (not inside)
    - Feedthroughs at top plate interface (300K boundary)
    - Cryostat = aluminum vacuum vessel
    - Update vessel/plates material from 304L SS to 6061-T6 Al
2026-03-13 Add plastic isolation jacket to simplify ground isolation
    Plastic enclosure around cryostat prevents accidental cable contact
    with vessel body, eliminating manual assembly discipline requirements.
2026-03-13 Route feedthrough wiring through 40K before 4K stage
    Wires heat-sunk at radiation shield before reaching sample stage.
2026-03-13 Consolidate cryostat diagram with top plate subgraph
    - Move Pirani gauge and pressure relief into top plate
    - Merge into single cryostat box with nested top plate
2026-03-13 Fix ASCII diagram: cold head motor outside vacuum
    Motor housing sits on top plate, only cold finger penetrates vacuum.
    Also updated vessel material to Al.
2026-03-13 Document vessel material options: aluminum vs stainless
    - Aluminum (preferred): Atlas bimetal flanges + Al tube, non-magnetic
    - Stainless (fallback): Lesker COTS, works with FINEMET shielding
    - Added new subsection explaining trade-offs
2026-03-16 Add FreeCAD 3D models of cryostat assembly
    Create parametric CAD models for complete cryostat system:
    - RDK-101D cold head with M4 mounting holes for thermal straps
    - DN320CF vacuum vessel (550mm length, 320mm ID)
    - 300mm OD radiation shield with mounting tabs
    - 250mm diameter sample volume envelope
    - Alumina thermal break disk
    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
    [BMC401_cryocooler.stp, alumina-disk.FCStd, cryostat-assembly.FCStd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]
2026-03-16 Add server rack, compressor, and mounting frame to assembly
    New parts:
    - CNA-11R rackmount helium compressor (9U, 484x540x400mm)
    - 42U server rack (600x1100x2067mm, 19" rails)
    Assembly updates:
    - Cryostat mounted at U35 with sheet metal mounting frame
    - Solid plate frame with center cutout for vessel flange
    - Bent mounting tabs (4U) bolting to all 4 rack rails
    - Compressor positioned at U1-U10
    Based on SHI Cryogenics CNA-11R specs (compatible with RDK-101D).
    [cna-11r-compressor.FCStd, cryostat-assembly.FCStd, server-rack.FCStd]
2026-03-16 Add aluminum mounting frame to BOM
    6mm 6061-T6 aluminum plate with laser-cut center hole and bent
    mounting tabs. Supports cryostat from 19" rack rails.
2026-03-16 Add rack assembly screenshot and update CAD documentation
    - Add rack-assembly.png showing complete system in 42U rack
    - Update README with rack assembly section and screenshot
    - Add CNA-11R compressor and server rack dimension sources
    - Update folder structure to include new rack-related files
2026-03-16 Add working render section to cryostat assembly doc
    Links to rack-assembly.png screenshot showing complete system
    in 42U rack configuration.
2026-03-16 Add CAD render to design package and regenerate PDF
    - Add Appendix C with rack-assembly.png screenshot
    - Regenerate PDF with updated content
2026-03-16 Update design package PDF with renders and flowchart
    - Add title page render (cryo_rack_render.jpg)
    - Add CAD render appendix (rack-assembly.png)
    - Pre-render mermaid flowchart to PNG for PDF compatibility
    - Clean up title page layout
2026-03-24 Populate Vertiv BOM with rack, PDU, UPS, accessories, and grounding spec
    Override rack (VR3100) and PDU (VP8830 monitored) with Vertiv parts.
    Add UPS (GXT5-1500LVRT2UXL), shelves (VRA3000), cable managers (VRA1002),
    and blanking panels (VRA2002). Document the two-domain power/grounding
    architecture per ADR-004, including UPS role as line conditioner (always
    through battery) vs isolation transformer as galvanic break.
2026-03-24 Add STEP export to assembly script and track exported STEP file
    Add STEP export step to cryostat-assembly.py so running the script
    regenerates both the FCStd and STEP. Update .gitignore to track
    STEP files in exports/ for sharing with vendors and machine shops.
    Re-exported assembly is 340 KB with all parts at current dimensions.
    [cryostat-assembly.FCStd, cryostat-assembly.step]
2026-03-31 Add part numbers, vendor links, and raw stock refs to BOM
    Resolved 24 missing part numbers down to 3 (all deferred qty=0 items).
    Key sourcing: Lesker (vessel, top plate, feedthroughs, gaskets), McMaster
    (copper braid), Lake Shore (PhBr wire), CoorsTek (alumina disk), Pfeiffer
    PM015888-T (turbo station), CMR Direct (indium wire). Promoted Vertiv
    VR3100/VP8830 from site override to base BOM. Replaced $728 UHV burst
    disc with $60 bmotiontech spring relief valve (UHV unnecessary with
    Viton seals + cryopumping). Added raw stock links and CUSTOM/DIY labels
    for machined parts (radiation shield, sample stage, mounting frame, PCB).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
2026-04-12 Add BOM schema validation and completeness checker (task 0103)
    JSON Schema for base and site-override BOM YAML formats, a validation
    script that checks schema conformance and flags procurement completeness
    gaps (missing part numbers, lead times, unit prices), and a pytest suite
    with 44 tests covering valid/invalid BOMs, field-level completeness,
    site overrides, and integration against the real BOM data.
2026-04-12 Add cryogenic thermal budget calculator (task 0105)
    Parameterized Python calculator that computes heat loads per subsystem
    (DC wiring, RF coax, radiation with MLI, mechanical supports, ground
    isolation disk, optical I/O placeholder, DUT) and compares totals against
    the RDK-101D cryocooler capacity at both stages.
    Results: 2nd stage at ~22% utilization (22 mW / 100 mW), 1st stage at
    ~22% (667 mW / 3000 mW). Both stages have >75% margin, confirming the
    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
2026-04-12 Switch mechanical supports from SS304 to G10 fiberglass composite
    G10 conductivity integrals (NIST/Woodcraft) are ~10x lower than SS304,
    reducing mechanical support heat load from 549 mW to 114 mW. Solid G10
    rods replace thin-wall SS tubes (acceptable cross-section because k is
    so much lower). Grand total drops from 689 mW to 254 mW.
    New budget: 1st stage 8.2% utilized (was 22.2%), 2nd stage 7.7% (was 21.9%).
    Also fix hardcoded "SS304" label in thermal_budget.py detail strings to
    read material name from YAML inputs instead.
    [thermal_inputs.yaml]
2026-04-21 Add GitHub Actions CI workflow for BOM validation and PDF generation
    Validates BOM YAML against schema, runs pytest suite, generates BOM
    summary, and builds the PDF design package as a downloadable artifact.
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2026-04-29 Add signal chain simulator and tests
    Implements the cryogenic signal chain simulation tool for analyzing
    amplifier cascades, noise figures, and thermal budgets from 4K to 300K.
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2026-05-17 Pin scripts/requirements.txt to exact versions and add lockfile
    Replace >= constraints with == pins and add scripts/requirements.lock
    generated by `uv pip compile` capturing the full 23-package transitive
    closure. CI now installs from the lockfile. README documents the
    regeneration workflow.
    Refs: planner task 0188.
2026-05-17 docs: fix broken ADR-004 link in cryostat-assembly
    The link target ../decisions/004-ground-isolation.md doesn't exist
    in this repo and was breaking the AM wiki build (which sets
    onBrokenMarkdownLinks: 'throw'). Convert to an inline reference
    to the same path so the prose still points readers to the (future)
    ADR without claiming the file already exists.
2026-05-17 signal chain: add brand-compliant waterfall plot and scenario tests
    Builds on the existing scripts/signal_chain.py cascade analysis (commit
    eb70606) with the deliverables called out in TASKS/0185 review:
    - scripts/signal_chain_plot.py renders a brand-compliant (BRAND.md)
    waterfall chart of per-stage signal amplitude (dBuA), noise floor,
    and SNR. Three named scenarios: nominal / worst_loss / worst_noise.
    - docs/assets/signal_chain_waterfall.png committed as the canonical
    fixture; worst_loss and worst_noise variants also committed for
    design-margin reference.
    - tests/test_signal_chain.py grows from 39 to 44 tests:
    TestScenarios::{nominal,worst_loss,worst_noise}_* assert headline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
2026-05-17 signal chain plot: drop AM-specific branding, keep quality principles
    cryo-rack is CBA-first / shared; remove AM brand palette (#4d65ff accent,
    Geist font preference, "AM internal" citation, "Adiabatic Machines BRAND.md"
    references). Use a neutral scientific palette (tab:blue / tab:red), generic
    sans-serif fallback chain, and a plain source citation.
    Quality principles retained: white background, hidden top/right spines,
    subtle grid (alpha=0.3), 16:9 at 150 DPI, bold title + labels with units,
    source citation bottom-right.
    3 PNG fixtures regenerated. 44/44 tests pass.
